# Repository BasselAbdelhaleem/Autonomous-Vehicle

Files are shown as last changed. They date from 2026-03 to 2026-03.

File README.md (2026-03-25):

# 🚗 Autonomous Vehicle — From Children's Ride-On to Self-Driving Robot

> A fully autonomous ground vehicle built from the ground up — hardware hacked, software architected, and driven by nothing but code.

---

## 🧠 What Is This?

What started as a toy was transformed into a fully functional self-driving platform — complete with real-time localization, path planning, and closed-loop motor control — using a layered hardware-software architecture inspired by industry-standard autonomous vehicle design.

This project demonstrates mastery across the **full robotics stack**: mechanical modification, embedded systems, low-level control theory, and high-level ROS-based autonomy.

---

## 🎥 Demo

https://github.com/user-attachments/assets/c8e445ca-634c-4c97-9aab-e79757e4ddac

---

## ✨ Key Features

- **Full hardware conversion** of a commercial ride-on car into an autonomous platform
- **Closed-loop speed & steering control** using encoder odometry and IMU heading
- **Pure Pursuit path tracking** for smooth, accurate trajectory following
- **ROS-based autonomy stack** handling navigation, localization, and path planning
- **Layered control architecture** separating high-level planning from low-level actuation
- **Real-time serial communication** between Raspberry Pi and Arduino over UART
- **Gazebo simulation environment** for algorithm validation, running in parallel with hardware development

---

## 🏗️ System Architecture

The system is split into three distinct layers, mirroring professional autonomous vehicle design:

```
┌─────────────────────────────────────────────────┐
│           HIGH-LEVEL  (Raspberry Pi)            │
│  ROS Navigation · Path Planning · Localization  │
│          Pure Pursuit Controller                │
└────────────────────┬────────────────────────────┘
                     │ UART / Serial
┌────────────────────▼────────────────────────────┐
│          LOW-LEVEL  (Arduino Uno)               │
│   Speed PID · Servo Angle · Motor Driver PWM   │
└────────────────────┬────────────────────────────┘
                     │
┌────────────────────▼────────────────────────────┐
│            SENSING  (Arduino Nano)              │
│     IMU Heading · Encoder Angle · Feedback      │
└─────────────────────────────────────────────────┘
```

---

## 🔧 Hardware

### Platform
| Component | Details |
|---|---|
| **Base Vehicle** | Children's electric ride-on car |
| **Steering** | OEM steering wheel removed → Servo motor |
| **Drive** | Original DC motors retained, controlled via motor driver |
| **Odometry** | Rotary encoder mounted on rear axle via belt drive |
| **Heading** | IMU (Inertial Measurement Unit) |

### Electronics
| Component | Role |
|---|---|
| **Raspberry Pi** | High-level autonomy (ROS) |
| **Arduino Uno** | Low-level motor & servo control |
| **Arduino Nano** | Sensor reading (IMU + encoder) |
| **Motor Driver** | PWM voltage control to drive wheels |
| **Servo Motor** | Steering actuation |
| **Rotary Encoder** | Wheel speed & distance measurement |
| **IMU** | Yaw/heading estimation |

### Mechanical Modifications
- Steering column disassembled; servo motor coupled to the steering linkage
- Belt-and-pulley transmission added to the rear axle to interface the encoder without disrupting the drivetrain
- Electronics bay fabricated and mounted to the chassis

---

## 💻 Software Stack

### High-Level — Raspberry Pi (ROS)

The Raspberry Pi runs the full ROS navigation stack:

- **Localization**: Dead-reckoning using wheel encoder odometry fused with IMU heading data. Pose estimated by integrating velocity and angular rate over time.
- **Path Planning**: Waypoint-based global path generation.
- **Path Tracking**: **Pure Pursuit controller** — computes the required steering angle to track a look-ahead point on the desired path, producing smooth and stable trajectory following.
- **Communication**: Publishes target speed and steering commands to the Arduino Uno over serial.

```
ROS Topics:
  /odom          → Localization (encoder + IMU fusion)
  /cmd_vel       → Velocity commands to low-level controller
  /path          → Planned trajectory
  /imu/data      → Raw IMU readings
```

### Low-Level — Arduino Uno

Responsible for translating high-level commands into physical actuation:

- Receives **target speed** and **servo angle** from Raspberry Pi over UART
- Runs a **PID speed controller**: compares target speed against encoder feedback and outputs the appropriate PWM voltage to the motor driver
- Drives the **servo motor** to the commanded steering angle
- Sends sensor feedback back upstream

### Sensing Layer — Arduino Nano

Dedicated sensor node for clean, low-latency hardware reads:

- Reads **IMU** for real-time heading (yaw)
- Reads **rotary encoder** for wheel angle and velocity
- Streams data to the Arduino Uno for processing and forwarding

---

## 📐 Control Theory

### Pure Pursuit Path Tracking

The Pure Pursuit algorithm selects a **look-ahead point** on the reference path at a fixed distance ahead of the vehicle and computes the required steering angle using the geometric relationship:

```
δ = arctan(2 * L * sin(α) / ld)

Where:
  δ  = steering angle
  L  = vehicle wheelbase
  α  = angle between vehicle heading and look-ahead point
  ld = look-ahead distance
```

The look-ahead distance was tuned experimentally to balance responsiveness and stability at the vehicle's operating speed.

### Speed PID

A discrete PID controller on the Arduino Uno regulates wheel speed:

```
u(t) = Kp·e(t) + Ki·∫e(t)dt + Kd·de/dt

Where:
  e(t) = target_speed − measured_speed (from encoder)
  u(t) = PWM duty cycle → motor driver
```

---

## 🖥️ Simulation — ROS + Gazebo
 
A key part of the development workflow was running the path planning software in a **Gazebo simulation environment in parallel with real hardware development**. This allowed us to iterate on the planning algorithms rapidly and validate behavior before every deployment on the physical vehicle — a practice standard in professional robotics engineering.
 
### What Was Simulated
 
Rather than simulating the full vehicle physics, we focused the simulation on what mattered most: **validating the path planning logic in a realistic spatial environment**.
 
- **Custom Gazebo World**: A purpose-built environment was designed to replicate the real-world test area, including obstacles and boundary constraints. This gave the planner a geometrically faithful space to operate in.
- **Path Planning Validation**: The Pure Pursuit controller and waypoint navigation pipeline were run inside Gazebo, allowing us to observe trajectory tracking behavior, tune look-ahead distance, and catch edge cases — all without touching the hardware.
- **Parallel Development**: Simulation and hardware work ran simultaneously. Insights from the simulator directly informed control parameter tuning on the real vehicle, and hardware limitations in turn shaped how the simulation environment was refined.
 
### Why This Matters
 
Simulation-driven development is the industry standard in autonomous systems — used by teams at Waymo, NVIDIA, and virtually every robotics company to de-risk hardware testing. Building this workflow from scratch demonstrates not just coding ability, but **engineering process maturity**.
 
### Simulation vs. Real World
 
| Aspect | Simulation (Gazebo) | Real Vehicle |
|---|---|---|
| **Environment** | Custom Gazebo world | Physical test area |
| **Path Planning** | ✅ Full pipeline | ✅ Full pipeline |
| **Localization** | Simulated ground truth | Encoder + IMU dead-reckoning |
| **Motor Control** | Not simulated | Arduino Uno PID |
| **Purpose** | Algorithm validation & tuning | End-to-end system validation |
 
---

## 📁 Repository Structure

```
Autonomous Vehicle/
├── arduino/
│   ├── nano_sensor_node/       # IMU + encoder reading (Arduino Nano)
│   └── uno_low_level_control/  # PID speed control + servo (Arduino Uno)
├── hardware/                   # 3D models of hardware modifications
├── media/                      # Demo videos and images
├── ros/
│   └── build/
│   └── devel/
│   └── src/
│       └── communication/      # ROS ↔ Arduino communication
│       ├── localization/       # Odometry + IMU fusion
│       ├── navigation/         # Path planning & waypoint management
│       ├── path_planning/      # Pure Pursuit controller
├── simulation/                 # ROS + Gazebo files
└── README.md
```

## 🧩 Skills Demonstrated

This project touches every layer of a real autonomous system — making it directly relevant to roles in **robotics engineering**, **autonomous systems**, and **embedded control**:

| Domain | Demonstrated Skills |
|---|---|
| **Embedded Systems** | Arduino firmware, UART communication, interrupt-driven encoder reading |
| **Control Theory** | PID speed control, Pure Pursuit geometric path tracking |
| **ROS** | Node architecture, topic pub/sub, rosserial, launch files |
| **Sensor Fusion** | IMU + encoder dead-reckoning for pose estimation |
| **Mechanical Design** | Belt-drive encoder mounting, servo integration, chassis modification |
| **System Architecture** | 3-layer hierarchical control design (sensing → low-level → high-level) |
| **Simulation** | Custom Gazebo world design, parallel sim-hardware development workflow |

---

## 📬 Contact

Questions, collaborations, or just want to talk robots?

📧 bassel.abdelhaleem@gmail.com
🔗 [LinkedIn]([https://linkedin.com/in/yourprofile](https://linkedin.com/in/bassel-abdelhaleem-66a898216))

---

<p align="center">
  <i>Built with curiosity, soldered with patience, and driven by code.</i>
</p>

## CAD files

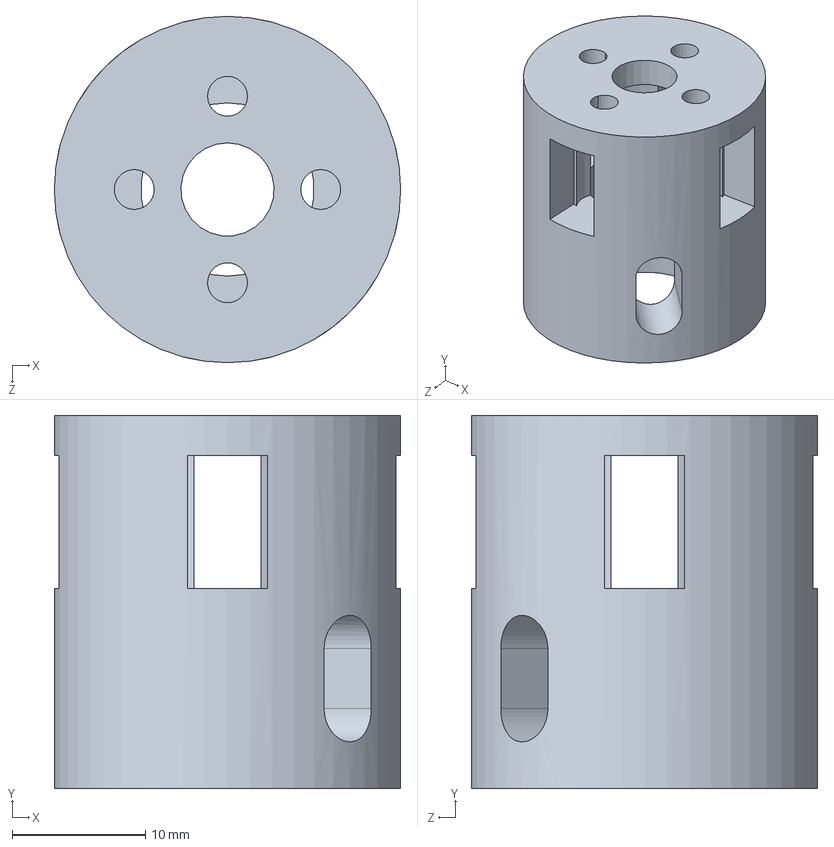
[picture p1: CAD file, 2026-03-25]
hardware/Steering Sleeve.SLDPRT
26.0 x 28.0 x 26.0 mm

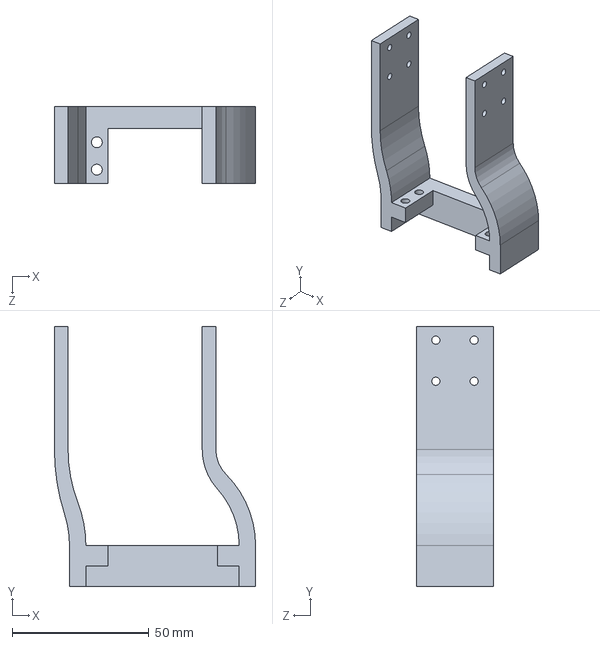
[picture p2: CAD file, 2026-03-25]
hardware/Servo Mount.SLDPRT
73.5 x 95.0 x 28.0 mm

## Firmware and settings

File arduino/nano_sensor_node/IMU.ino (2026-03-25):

void IMUinit() {
  //DESCRIPTION: Initialize IMU
  if (!IMU.begin()) {
    while (true)
      ;
  }
  delay(15);
}

void getIMUdata() {
  //DESCRIPTION: Request full dataset from IMU

  //Accelerometer
  if (IMU.accelerationAvailable()) {
    IMU.readAcceleration(AccX, AccY, AccZ);
    AccX = AccX - AccErrorX;
    AccY = AccY - AccErrorY;
    AccY = AccY - AccErrorZ;
    //Correct the outputs with the calculated error values
    /*
    //This was used to suppress noise.  However, it just slows things down.  There is already internal filters to the IMU.
    AccX = (1.0 - Accel_filter) * AccX_prev + Accel_filter * AccX;
    AccY = (1.0 - Accel_filter) * AccY_prev + Accel_filter * AccY;
    AccZ = (1.0 - Accel_filter) * AccZ_prev + Accel_filter * AccZ;
    AccX_prev = AccX;
    AccY_prev = AccY;
    AccZ_prev = AccZ;
    */
  } else return;
  if (IMU.gyroscopeAvailable()) {
    //Gyro
    IMU.readGyroscope(GyroX, GyroY, GyroZ);
    //Correct the outputs with the calculated error values
    GyroX = GyroX - GyroErrorX;
    GyroY = GyroY - GyroErrorY;
    GyroZ = GyroZ - GyroErrorZ;
    /*
    //This was used to suppress noise.  However, it just slows things down.  There is already internal filters to the IMU.
    GyroX = (1.0 - Gyro_filter) * GyroX_prev + Gyro_filter * GyroX;
    GyroY = (1.0 - Gyro_filter) * GyroY_prev + Gyro_filter * GyroY;
    GyroZ = (1.0 - Gyro_filter) * GyroZ_prev + Gyro_filter * GyroZ;
    GyroX_prev = GyroX;
    GyroY_prev = GyroY;
    GyroZ_prev = GyroZ;
    */
  }
}

void Madgwick6DOF(float gx, float gy, float gz, float ax, float ay, float az) {
  //DESCRIPTION: Attitude estimation through sensor fusion - 6DOF
  /*
   * See description of Madgwick() for more information. This is a 6DOF implimentation for when magnetometer data is not
   * available (for example when using the recommended MPU6050 IMU for the default setup).
   */
  float recipNorm;
  float s0, s1, s2, s3;
  float qDot1, qDot2, qDot3, qDot4;
  float _2q0, _2q1, _2q2, _2q3, _4q0, _4q1, _4q2, _8q1, _8q2, q0q0, q1q1, q2q2, q3q3;

  //Convert gyroscope degrees/sec to radians/sec
  gx *= 0.0174533f;
  gy *= 0.0174533f;
  gz *= 0.0174533f;

  //Rate of change of quaternion from gyroscope
  qDot1 = 0.5f * (-q1 * gx - q2 * gy - q3 * gz);
  qDot2 = 0.5f * (q0 * gx + q2 * gz - q3 * gy);
  qDot3 = 0.5f * (q0 * gy - q1 * gz + q3 * gx);
  qDot4 = 0.5f * (q0 * gz + q1 * gy - q2 * gx);

  //Compute feedback only if accelerometer measurement valid (avoids NaN in accelerometer normalisation)
  if (!((ax == 0.0f) && (ay == 0.0f) && (az == 0.0f))) {
    //Normalise accelerometer measurement
    recipNorm = invSqrt(ax * ax + ay * ay + az * az);
    ax *= recipNorm;
    ay *= recipNorm;
    az *= recipNorm;

    //Auxiliary variables to avoid repeated arithmetic
    _2q0 = 2.0f * q0;
    _2q1 = 2.0f * q1;
    _2q2 = 2.0f * q2;
    _2q3 = 2.0f * q3;
    _4q0 = 4.0f * q0;
    _4q1 = 4.0f * q1;
    _4q2 = 4.0f * q2;
    _8q1 = 8.0f * q1;
    _8q2 = 8.0f * q2;
    q0q0 = q0 * q0;
    q1q1 = q1 * q1;
    q2q2 = q2 * q2;
    q3q3 = q3 * q3;

    //Gradient decent algorithm corrective step
    s0 = _4q0 * q2q2 + _2q2 * ax + _4q0 * q1q1 - _2q1 * ay;
    s1 = _4q1 * q3q3 - _2q3 * ax + 4.0f * q0q0 * q1 - _2q0 * ay - _4q1 + _8q1 * q1q1 + _8q1 * q2q2 + _4q1 * az;
    s2 = 4.0f * q0q0 * q2 + _2q0 * ax + _4q2 * q3q3 - _2q3 * ay - _4q2 + _8q2 * q1q1 + _8q2 * q2q2 + _4q2 * az;
    s3 = 4.0f * q1q1 * q3 - _2q1 * ax + 4.0f * q2q2 * q3 - _2q2 * ay;
    recipNorm = invSqrt(s0 * s0 + s1 * s1 + s2 * s2 + s3 * s3);  //normalise step magnitude
    s0 *= recipNorm;
    s1 *= recipNorm;
    s2 *= recipNorm;
    s3 *= recipNorm;

    //Apply feedback step
    qDot1 -= B_madgwick * s0;
    qDot2 -= B_madgwick * s1;
    qDot3 -= B_madgwick * s2;
    qDot4 -= B_madgwick * s3;
  }

  //Integrate rate of change of quaternion to yield quaternion
  q0 += qDot1 * deltaTime;
  q1 += qDot2 * deltaTime;
  q2 += qDot3 * deltaTime;
  q3 += qDot4 * deltaTime;

  //Normalise quaternion
  recipNorm = invSqrt(q0 * q0 + q1 * q1 + q2 * q2 + q3 * q3);
  q0 *= recipNorm;
  q1 *= recipNorm;
  q2 *= recipNorm;
  q3 *= recipNorm;

  //Compute angles
  roll_IMU = atan2(q0 * q1 + q2 * q3, 0.5f - q1 * q1 - q2 * q2) * 57.29577951;  //degrees
  pitch_IMU = -asin(-2.0f * (q1 * q3 - q0 * q2)) * 57.29577951;                 //degrees
  yaw_IMU = -atan2(q1 * q2 + q0 * q3, 0.5f - q2 * q2 - q3 * q3) * 57.29577951;  //degrees
}

void tick() {
  //Keep track of what time it is and how much time has elapsed since the last loop
  prev_time = current_time;
  current_time = micros();
  deltaTime = (current_time - prev_time) / 1000000.0;  //division takes it from micros to seconds.  1000000 ms=1 second
}

void tock() {
  //DESCRIPTION: Regulate main loop rate to specified frequency in Hz
  /*
   * It's good to operate at a constant loop rate for filters to remain stable and whatnot. Interrupt routines running in the
   * background cause the loop rate to fluctuate. This function basically just waits at the end of every loop iteration until 
   * the correct time has passed since the start of the current loop for the desired loop rate in Hz. I have matched 
   * it just below the Gyro update frequency.  invFreq is set at the top of the code.
   */
  //Sit in loop until appropriate time has passed while checking for any WiFi client activity.
  while (invFreq > (micros() - current_time)) {
    //if (ALLOW_WIFI&&throttle_is_cut) loopWiFi();
  };
}

float invSqrt(float x) {
  //Fast inverse sqrt for madgwick filter
  /*
  float halfx = 0.5f * x;
  float y = x;
  long i = *(long*)&y;
  i = 0x5f3759df - (i>>1);
  y = *(float*)&i;
  y = y * (1.5f - (halfx * y * y));
  y = y * (1.5f - (halfx * y * y));
  return y;
  */
  /*
  //alternate form:
  unsigned int i = 0x5F1F1412 - (*(unsigned int*)&x >> 1);
  float tmp = *(float*)&i;
  float y = tmp * (1.69000231f - 0.714158168f * x * tmp * tmp);
  return y;
  */
  return 1.0 / sqrtf(x);  //Teensy is fast enough to just take the compute penalty lol suck it arduino nano
}
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

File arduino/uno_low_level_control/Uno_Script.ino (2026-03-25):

//#include <SoftwareSerial.h>
#include <Servo.h>
//#include <Encoder.h>
//#define ENCODER_USE_INTERRUPTS

//Encoder myEnc(2, 3);

//const int rxPin = 7;
//const int txPin = 8;
//SoftwareSerial Serial1 (rxPin, txPin);

Servo servo;

long currentPosition;
float deg;
float curPosRad;
float prevPosRad;
float actualVelocity;
float actualRpm;
float prevActualRpm;
float Rpm_filt;
long time;
float deltaTime;
long prevTime;


bool led = false;

// Define motor control pins
const int motorPin1 = 11;  // Connect this to L EN on the motor driver
const int motorPin2 = 12;  // Connect this to R EN on the motor driver

// Define motor speed control pins
const int motorSpeedPin1 = 5;  // Connect this to the enable pin 1 of Motor
const int motorSpeedPin2 = 6;  // Connect this to the enable pin 2 of Motor


const int servoPin = 9;  // Connect steering servo to pin 9


// desired velocity & angle  message received from Raspberry Pi

String desiredData;
int PwmDes;
int angleDes;

void setup()
{
  Serial.begin(115200);

  // Software Serial pins & baudrate
  //pinMode(rxPin, INPUT);
  //pinMode(txPin, OUTPUT);
  //Serial1.begin(115200);

  // Initialize motor control pins as outputs
  pinMode(motorPin1, OUTPUT);
  pinMode(motorPin2, OUTPUT);
  pinMode(motorSpeedPin1, OUTPUT);
  pinMode(motorSpeedPin2, OUTPUT);
  pinMode(LED_BUILTIN, OUTPUT);

  servo.attach(servoPin);
}

void loop()
{
  // Read the incoming data
  //String data = Serial.readStringUntil('\r\n');

  //String velocityDes = data.substring(0, data.indexOf('/'));
  //String angleDes = data.substring(data.indexOf('/') + 1);
  
  //setTargetVelocity(velocityDes.toInt());
  if(Serial.available()>0){
    desiredData = Serial.readStringUntil('\r\n');
    // Split the received data into velocity & angle
    PwmDes = desiredData.substring(0, desiredData.indexOf('/')).toInt();
    //PwmDes=100;
  }

  steer(PwmDes);

  //Rpm_filt = computeActualRpm();

  //Serial1.println(Rpm_filt);

//  Serial.print(-100);
//  Serial.print("\t");
//  Serial.print("\t");
//  Serial.print(Rpm_filt);
//  Serial.print("\t");
//  Serial.print(100);
//  Serial.println(angleDes);
    
}
/*
float computeActualRpm() {
  currentPosition = myEnc.read();
  deg = map(currentPosition, 0, 1450, 0, 360);
  curPosRad = deg * (PI / 180);

  time = micros();
  deltaTime = ((float)(time - prevTime)) / 1.0e6;
  //Serial.println(deltaTime);
  //Serial.print(curPosRad);
  //Serial.print("    ");
  //Serial.println(prevPosRad);
  actualVelocity = (curPosRad - prevPosRad) / deltaTime;  // rad/sec
  prevActualRpm = actualRpm;
  actualRpm = actualVelocity * (60 / (2 * PI));  //rpm
  prevPosRad = curPosRad;
  prevTime = time;
  delay(3);
  Rpm_filt = 0.854 * Rpm_filt + 0.0728 * actualRpm + 0.0728 * prevActualRpm;
  return Rpm_filt;
}
*/
void moveForward(int motorSpeed) {
  //Serial.print("Moving forward: ");
  //Serial.println(motorSpeed);

  // Set motor directions for forward motion
  digitalWrite(motorPin1, LOW);
  digitalWrite(motorPin2, HIGH);

  // Set PWM value to control motor speed (255 out of 255 maximum)
  analogWrite(motorSpeedPin1, motorSpeed);
  analogWrite(motorSpeedPin2, motorSpeed);
}

void moveBackward(int motorSpeed) {
  //Serial.print("Moving backward: ");
  //Serial.println(motorSpeed);


  // Set motor directions for backward motion
  digitalWrite(motorPin1, HIGH);
  digitalWrite(motorPin2, LOW);

  // Set PWM value to control motor speed (150 out of 255 maximum)
  analogWrite(motorSpeedPin1, motorSpeed);
  analogWrite(motorSpeedPin2, motorSpeed);
}

void steer(int angle) {
  angle = map(angle, -45, 45, 45, 135);  // map input angle to servo angle range
  //Serial.print("Steering: ");
  Serial.println(angle);
  servo.write(angle);
}

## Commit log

2026-03-25 Rename Servo Mount.SLDPRT to Servo Mount.SLDPRT
    [Servo Mount.SLDPRT]
2026-03-25 Rename Steering Sleeve.SLDPRT to Steering Sleeve.SLDPRT
    [Steering Sleeve.SLDPRT]
